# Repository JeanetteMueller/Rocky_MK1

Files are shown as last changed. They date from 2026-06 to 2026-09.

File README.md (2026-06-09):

# Multi-leg Robot with Inverse Kinematics

A DIY walking robot with a configurable number of legs, fully 3D-printed and powered by an ESP32 microcontroller.

Have a look at

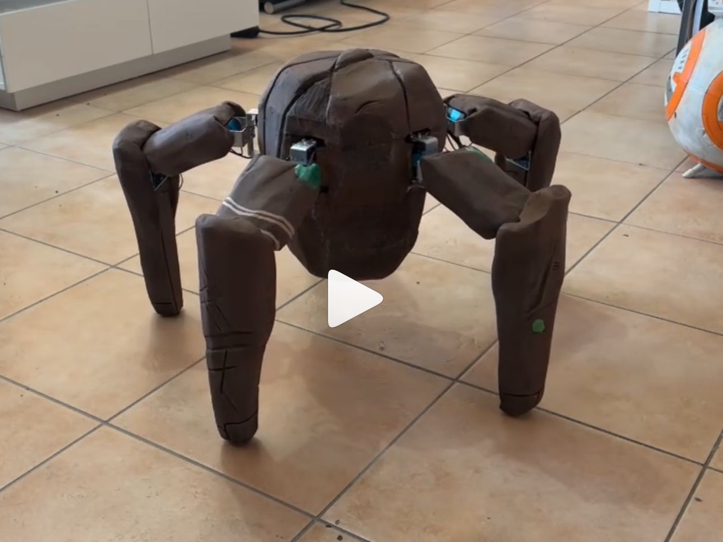
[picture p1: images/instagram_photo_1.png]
Instagram Post (https://www.instagram.com/reel/DXeBLnWDbUL/?igsh=MTJqa2dneTdlbXB5dA==)


## What is This?

This is a multi-legged walking robot designed to support **any leg count and any leg layout** you can imagine. Each leg is its own configurable object — its position around the body, its orientation, and its segment lengths can all be set individually. That means you are not limited to a symmetric pentapod or a classic hexapod: you can build a four-legged scout, a perfectly symmetric octopod, or something deliberately asymmetric with longer front legs, shorter back legs, or unusual angular spacing.

Every leg has three joints driven by three servo motors — Coxa (hip swing), Femur (hip lift), and Tibia (knee). All legs are coordinated so the robot can walk, turn, and perform gestures.

## Asymmetric Robots Are a First-Class Feature

The legs are no longer assumed to be evenly distributed. When constructing the robot, you pass in an array of `RobotLeg` objects, and each one gets its own parameters:

```cpp
static RobotLeg myLegs[NUMBER_OF_LEGS] = {
    RobotLeg(bodyRadius, coxaLength, femurLength, tibiaLength,
             baseFootExtend,     // distance from first servo axis to foot
             baseAngleDeg,       // where this leg sits on the body (degrees)
             rotationOffset),    // how the leg is mounted (degrees)
    // ... one entry per leg, each fully independent
};
```

This unlocks designs like:

- **Spider-style asymmetry:** longer reach in front, shorter rear legs
- **Custom layouts:** legs clustered on one side, or grouped in pairs
- **Mixed geometries:** different femur/tibia lengths per leg for specialized roles
- **Non-uniform spacing:** legs at any angle around the body, not just `360° / N`

The inverse kinematics, gait planning, and special-pose system all read each leg's parameters directly, so an asymmetric build behaves correctly without any special-case code.

## Design

**Body:** Round body with the legs arranged around the perimeter. In the default five-legged build, the body has a radius of approximately 104 mm (center to leg attachment point) and the legs are placed at 72° intervals — but neither the count nor the spacing is hard-wired into the math.

**Legs:** Each leg has three segments:

- **Coxa** — 54 mm, the short hip segment that swings the leg sideways
- **Femur** — 120 mm, the upper leg segment lifted by the second servo
- **Tibia** — 222.5 mm (217 mm shin + 5.5 mm rubber foot pad), the lower leg segment moved by the knee

**Brain:** An ESP32 microcontroller handles all motion calculations, drives the servos via a serial bus, and reads input from the remote control receiver.

**Shell:** All structural parts are 3D-printed.

## How Does It Move?

The robot uses **inverse kinematics** — instead of manually setting angles for each servo, you define where a foot should be in 3D space, and the required joint angles are calculated automatically using trigonometry (law of cosines). This keeps the feet planted on the ground even when the body height, tilt, or yaw changes.

When walking, the robot lifts one or two legs at a time while the remaining legs support the body and push it forward. At low speed, only one leg lifts per phase (more stable). At higher speed, two legs lift simultaneously (faster but less stable). The gait runs as a cyclic phase pattern that adapts automatically to the number of legs in the configuration.

In addition to walking, the robot supports **special poses** — predefined choreographed movements where a pair of legs leaves the gait cycle, moves into a custom position, holds it, and returns to the standing pose. This is used for waving, greeting gestures, or any other interactive behavior.

## Controls

The robot uses a **FlySky receiver (10 channel)** to connect to a FlySky transmitter. All inputs are transmitted to the ESP32 in real time over the IBUS protocol.

Inputs include:

- **Right stick:** walk direction and speed (or steering, depending on mode)
- **Left stick:** body tilt (pitch and roll)
- **Left potentiometer:** body height
- **Right potentiometer:** body yaw rotation
- **Switches:** mode switch (vehicle vs. strafing), special poses, gesture triggers

A switch on the transmitter toggles between two control schemes:

- **Vehicle mode:** forward/backward + steering, like a car
- **Strafing mode:** full directional control, like a tank or RC drone

## Specs

| | |
|---|---|
| **Legs** | Configurable (default build: 5) |
| **Servos per leg** | 3 (Coxa, Femur, Tibia) |
| **Microcontroller** | ESP32 |
| **Coxa length** | 54 mm |
| **Femur length** | 120 mm (default, per-leg configurable) |
| **Tibia length** | 222.5 mm (default, per-leg configurable) |
| **Body radius** | ~104 mm (default, center to leg attachment) |
| **Body height range** | 170–285 mm |
| **Max step width** | 230 mm |
| **Max body tilt** | ±20° |
| **Max body rotation (yaw)** | ±25° |
| **Communication** | FlySky receiver (IBUS) |
| **Servo bus** | Serial (SCServo) |
| **Shell** | 3D-printed |
| **Kinematics** | Inverse kinematics (law of cosines) |
| **Language** | C++ (Arduino framework) |

## Future Plans

- **Sensors:** IMU for automatic body leveling on uneven terrain, foot contact sensors for adaptive gait
- **Reinforcement learning:** Training an AI-driven gait, first in simulation (MuJoCo / PyBullet), then transferring to the real robot
- **Range sensor:** Front-facing ToF sensor for obstacle detection

## Build Notes

### Stuff to Buy

- 3 × leg-count ST3020 serial servos (15 for the default 5-leg build)
- Serial servo controller board
- ESP32 dev board
- FlySky 6/10 channel transmitter + receiver

### 3D Printing

Inside the STL folder you will find files for 3D printing. The end of each filename indicates how many copies to print — for example, a file ending in `x5` needs to be printed five times.

### Prepare the Servos

Use my programmer to assign the servo IDs (1 to N):
[https://github.com/JeanetteMueller/SerialServoIdProgrammer](https://github.com/JeanetteMueller/SerialServoIdProgrammer)

### Required Libraries

- [FlyskyIBUS](https://github.com/derdoktor667/FlyskyIBUS)
- [SCServo](https://github.com/workloads/scservo)

## License & Contact

This is a personal hobby project.

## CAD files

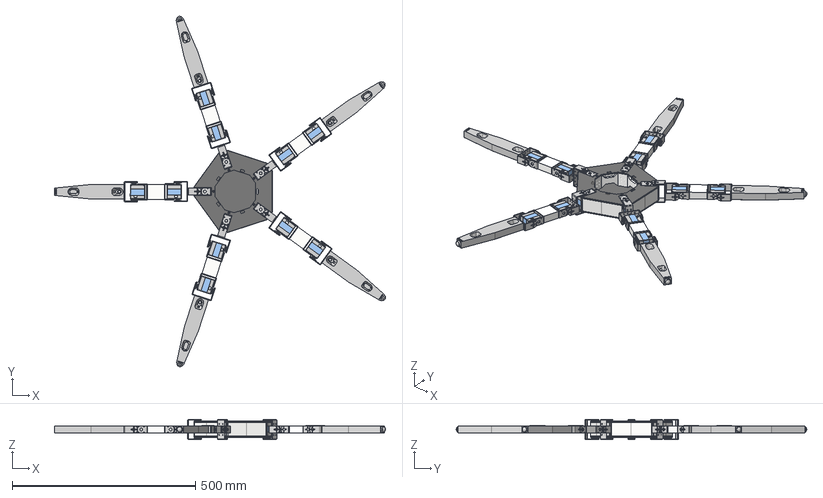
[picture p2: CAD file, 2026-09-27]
STEP/5LegBase v65.step
904.2 x 957.8 x 55.8 mm
SJ-WK00-0054-TOPCABINET_39 x 15
SJ-WK00-0057-BOTTOMCASE_45 x 15
SJ-WK00-0056-MIDDLECASE-TTL_79 x 15
OUTPUTGEAR_12 x 15
SC15-PCB-A_16 x 15
PAIZHING2-54_1 x 15
MAINPCB-PH2-AMP-20210107_1 x 15
FK-AP-019-20210309_1 x 15
WJ-DP00-0002-FK-AP-020_1_1 x 15
FK-US-001_1 x 15
FK-US-002_1 x 15
M20X30_3 x 60
frame
cover_top
cover_bottom
DruckTaster x 4

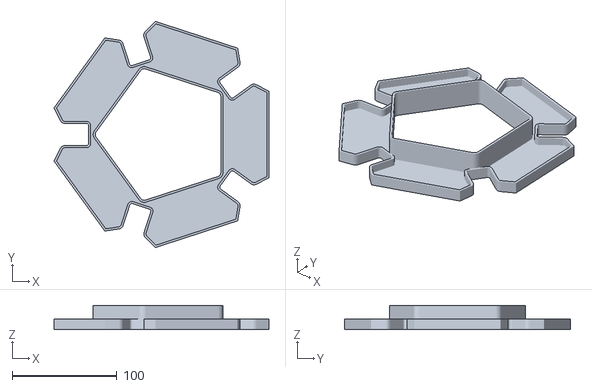
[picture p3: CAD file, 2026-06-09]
STL/TopBodyAddition.stl
205.1 x 215.7 x 23.0

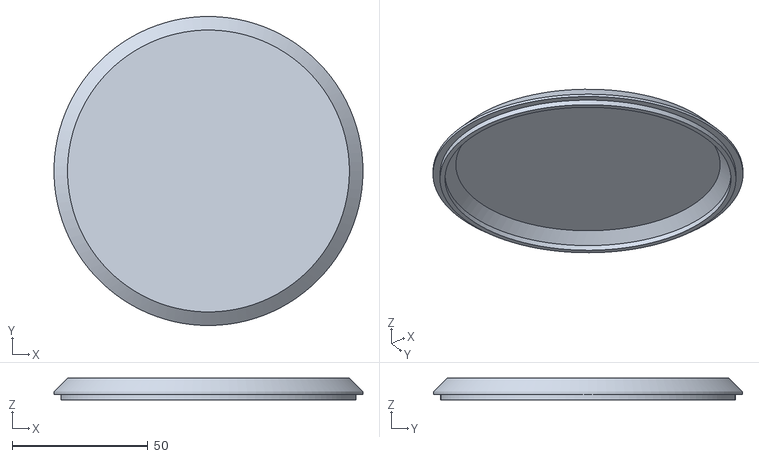
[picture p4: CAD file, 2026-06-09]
STL/head_cover.stl
114.0 x 114.0 x 8.00

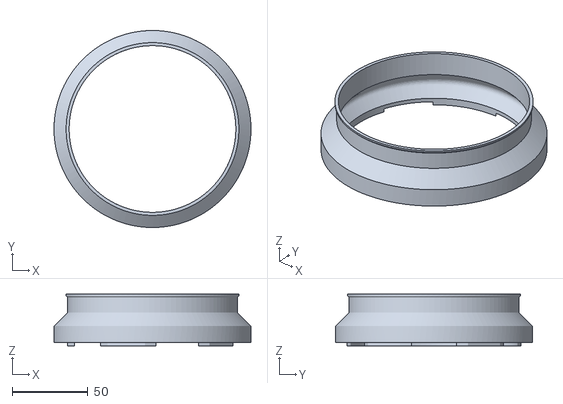
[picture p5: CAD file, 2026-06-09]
STL/head_body.stl
130.0 x 130.0 x 34.0

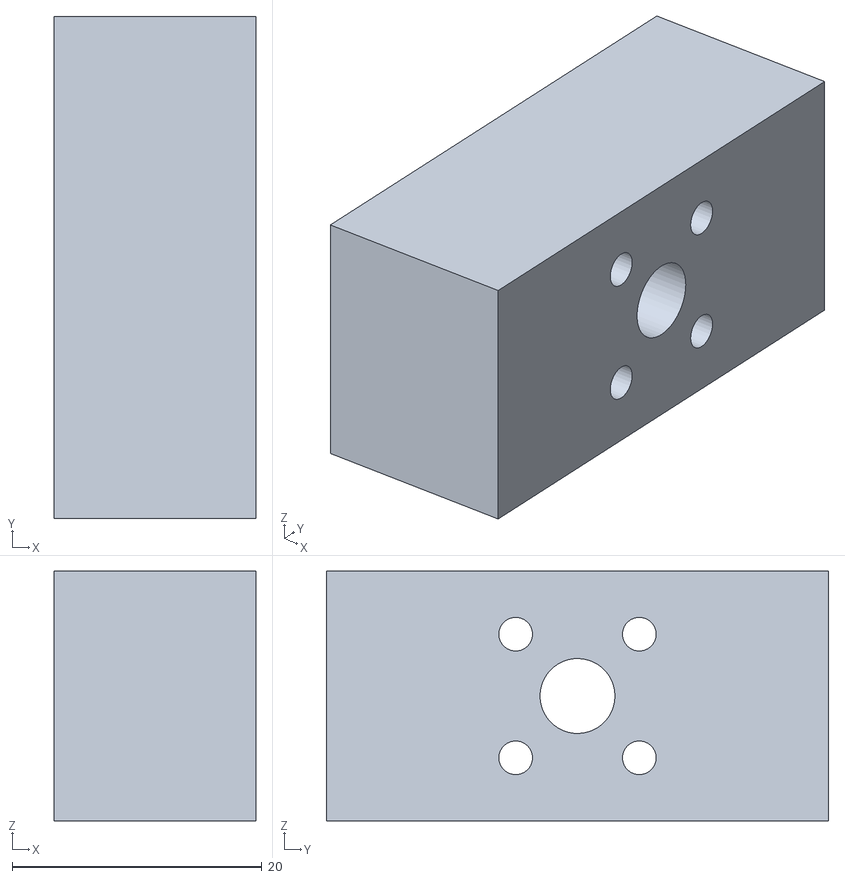
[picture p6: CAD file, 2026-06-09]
STL/thigh x5.stl
16.1 x 40.2 x 20.0

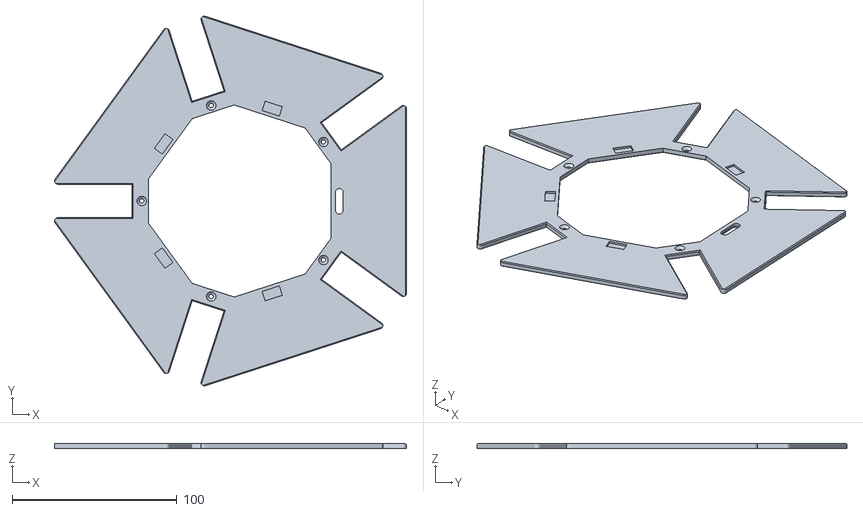
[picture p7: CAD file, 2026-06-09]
STL/cover_top.stl
213.9 x 224.7 x 3.00

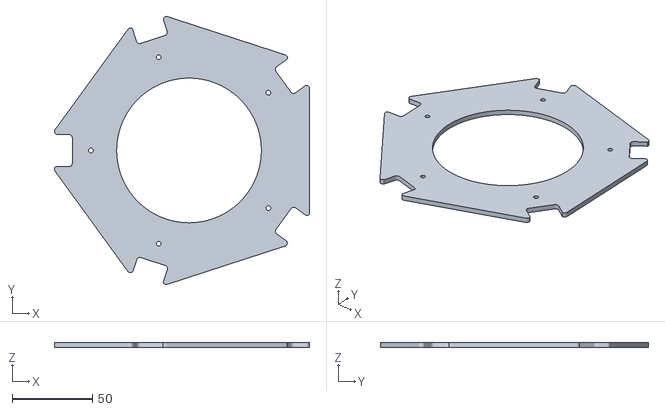
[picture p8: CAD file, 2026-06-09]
STL/UpperBodyAddition.stl
158.7 x 166.7 x 3.00

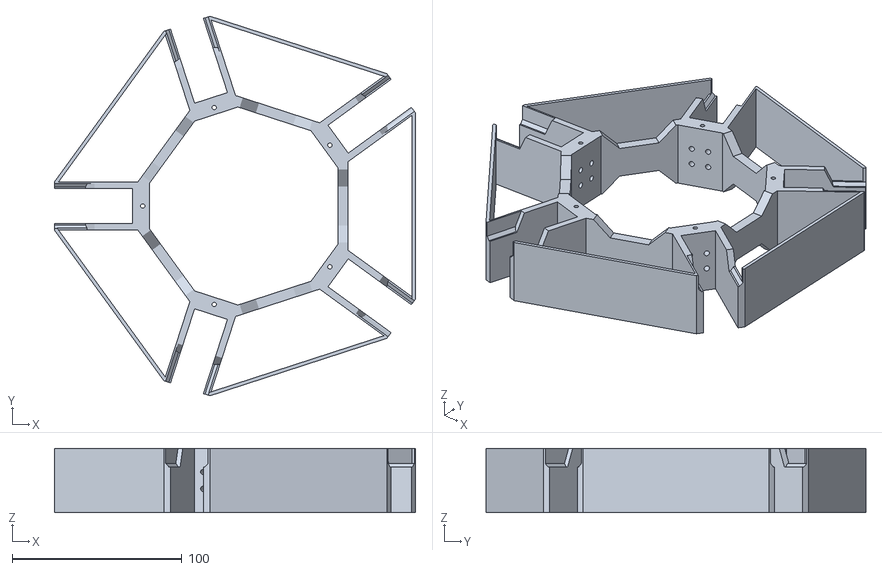
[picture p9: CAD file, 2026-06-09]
STL/frame.stl
212.8 x 223.8 x 38.0

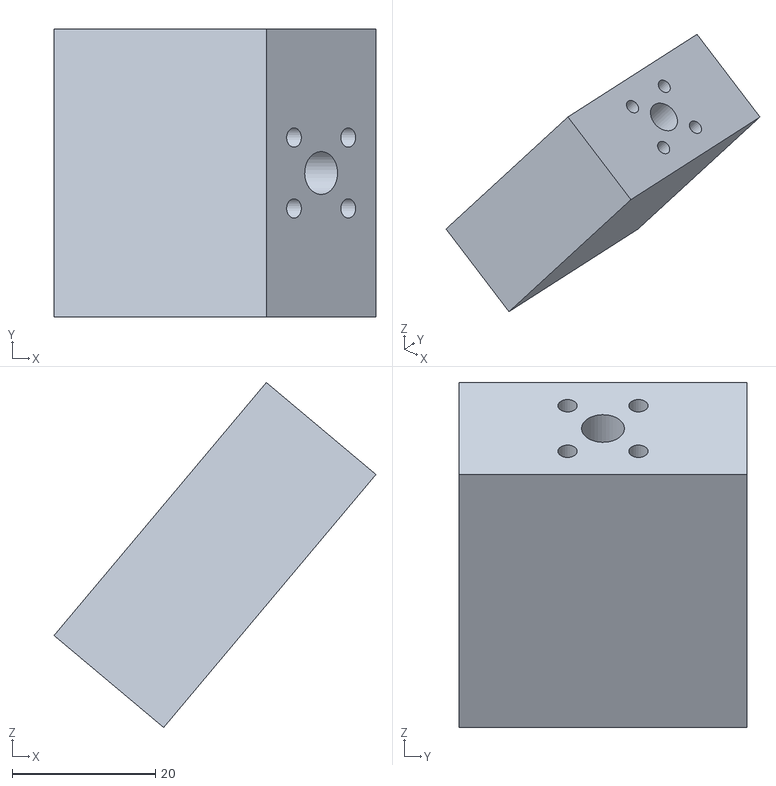
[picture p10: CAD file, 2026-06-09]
STL/thigh v2 x5.stl
45.0 x 40.2 x 48.2

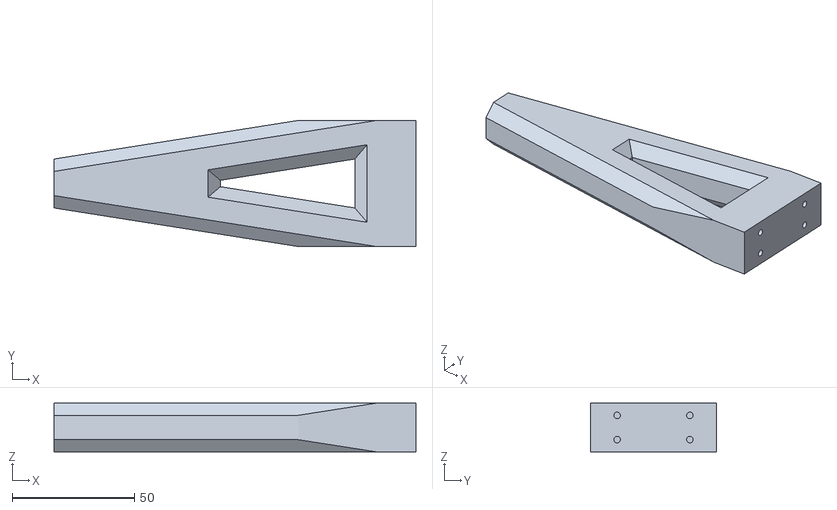
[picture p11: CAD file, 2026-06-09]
STL/shin x5.stl
148.0 x 51.6 x 20.0

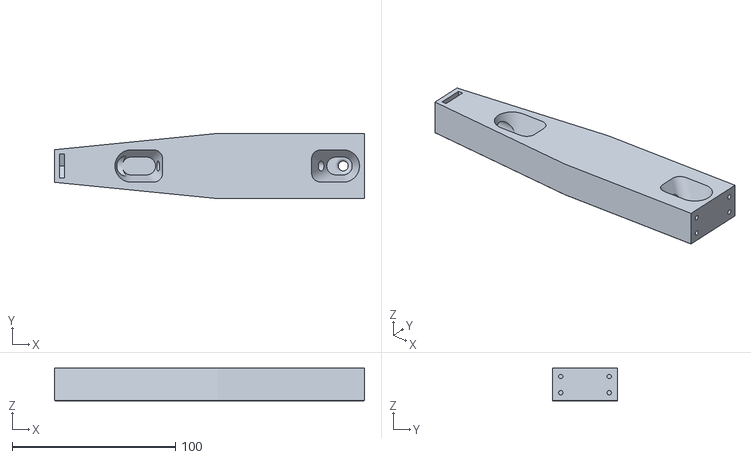
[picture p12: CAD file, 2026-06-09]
STL/shin v3 x5.stl
190.0 x 40.0 x 20.0

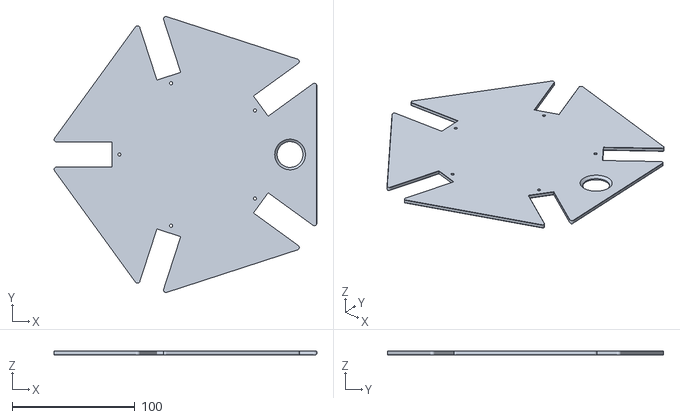
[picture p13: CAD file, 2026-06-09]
STL/cover_bottom.stl
213.9 x 224.7 x 3.00

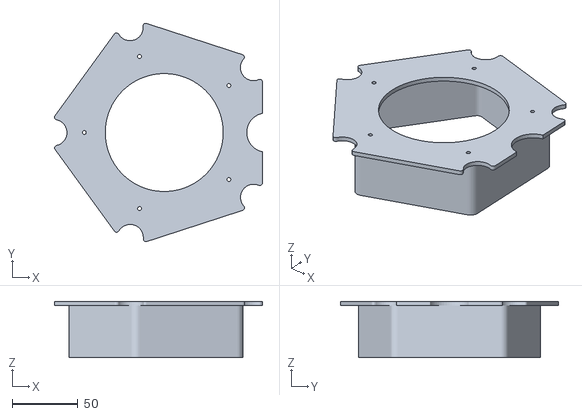
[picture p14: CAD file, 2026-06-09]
STL/LowerBodyAddition.stl
158.7 x 166.7 x 43.0

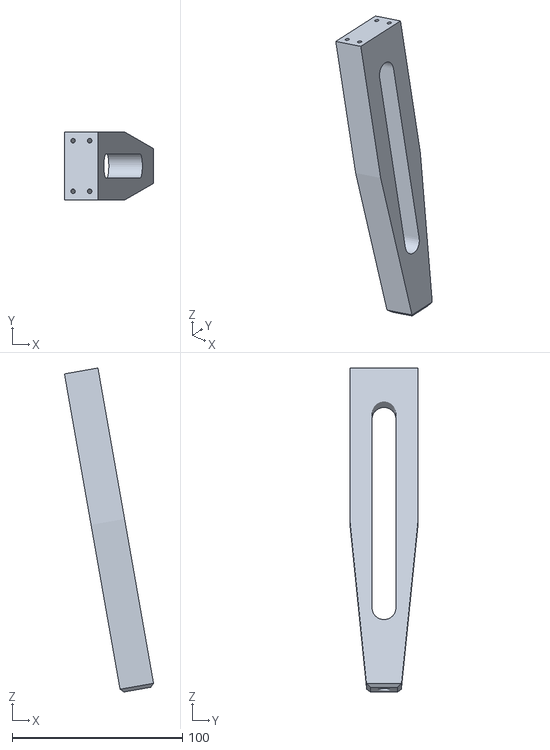
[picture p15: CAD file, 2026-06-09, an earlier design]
STL/shin v2 x5.stl
52.3 x 40.0 x 190.2

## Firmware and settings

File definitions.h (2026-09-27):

/**
 * definitions.h
 *
 * Basis Variablen
 *
 * Autor: Jeanette Müller
 * Datum: 2025
 */

bool debug = false;

SMS_STS st;

#define SERVO_NUM (NUMBER_OF_LEGS * 3) // Number of servos
// u8 servoIds[SERVO_NUM] = {1, 2, 3, 4, 5, 6, 7, 8, 9, 10, 11, 12, 13, 14, 15};
u8 servoIds[SERVO_NUM] = {5, 14, 15, 7, 8, 9, 4, 2, 3, 10, 11, 6, 13, 1, 12};
s16 newPosition[SERVO_NUM];
u16 newSpeed[SERVO_NUM];
u8 newAcc[SERVO_NUM];

const u16 speed = 4000;
const u8 acc = 0;

bool calibrated = false;

#include "../extraCalibrations.h"

// Timing
const uint16_t walkingStepCount = 60;
const uint16_t mainLoopDelay = 5;

// Sizes
const float bodyCenterToLegsCircleRadius = 104.175; // mm
const float coxaLength = 54.0;                      // mm
const float thighLength = 120.0;                    // mm
const float shinLength = 217.0 + 5.5;               // mm // shin + rubber pad
const float minStepHeight = 30.0;
const float centerOfMassShiftFactor = 0.4; // 0.0 = off, 1.0 = all the way to centroid

// Joint limits for Rocky (in degrees). These values used to be hard-coded in
// the library (LegAngles.h) and are now configured centrally here.
//                      { min,    max }
const LegLimits rockyLegLimits = {
    {-65.0, 65.0},   // coxa  (swing)
    {-130.0, 130.0}, // femur (lift)
    {-140.0, 140.0}  // tibia (knee)  = ±(180 - 40)
};

// Position
const float startBodyHeightOverGround = 160.0;            // mm
const float startLegExtend = 280.0;                       // mm
const float heightOffset = 0.0;

// Min/Max Values
const float maxTilt = 26.0;
const float maxRotation = 30.0;
const float maxStepWidth = 230.0;
const float minHeight = 170.0; // mm
const float maxHeight = 285.0; // mm
const float maxRotationBodyOnPoint = 260.0; // mm

// Offset
AxisOffset legAxisOffset = {0.0f, 0.0f};

// Conditions
const bool enableCenterOfMassShift = false;
bool multiLegMovement = true;

// Robot itself
RobotWithKinematics *robot;

// Legs
static RobotLeg myLegs[NUMBER_OF_LEGS] = {
    RobotLeg(
        bodyCenterToLegsCircleRadius, // body radius in mm
        coxaLength,                   // coxa length in mm
        thighLength,                  // thigh length in mm
        shinLength,                   // shin length in mm
        heightOffset,                 // offset from center of mass
        startLegExtend,               // distance of first servo axis to foot
        minStepHeight,                // min height of foot over ground when walking
        0,                            // degree of first servo from front of robot
        -2.0f * 0,
        rockyLegLimits,               // joint limits
        legAxisOffset                 // Lateral axial displacement of the knee {femur, tibia} in mm
        ),
    RobotLeg(
        bodyCenterToLegsCircleRadius, // body radius in mm
        coxaLength,                   // coxa length in mm
        thighLength,                  // thigh length in mm
        shinLength,                   // shin length in mm
        heightOffset,                 // offset from center of mass
        startLegExtend,               // distance of first servo axis to foot
        minStepHeight,                // min height of foot over ground when walking
        72,                           // degree of first servo from front of robot
        -2.0f * 72,
        rockyLegLimits,               // joint limits
        legAxisOffset                 // Lateral axial displacement of the knee {femur, tibia} in mm
        ),
    RobotLeg(
        bodyCenterToLegsCircleRadius, // body radius in mm
        coxaLength,                   // coxa length in mm
        thighLength,                  // thigh length in mm
        shinLength,                   // shin length in mm
        heightOffset,                 // offset from center of mass
        startLegExtend,               // distance of first servo axis to foot
        minStepHeight,                // min height of foot over ground when walking
        144,                          // degree of first servo from front of robot
        -2.0f * 144,
        rockyLegLimits,               // joint limits
        legAxisOffset                 // Lateral axial displacement of the knee {femur, tibia} in mm
        ),
    RobotLeg(
        bodyCenterToLegsCircleRadius, // body radius in mm
        coxaLength,                   // coxa length in mm
        thighLength,                  // thigh length in mm
        shinLength,                   // shin length in mm
        heightOffset,                 // offset from center of mass
        startLegExtend,               // distance of first servo axis to foot
        minStepHeight,                // min height of foot over ground when walking
        216,                          // degree of first servo from front of robot
        -2.0f * 216,
        rockyLegLimits,               // joint limits
        legAxisOffset                 // Lateral axial displacement of the knee {femur, tibia} in mm
        ),
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

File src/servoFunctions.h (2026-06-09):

/**
 * servoFunctions.h
 *
 * Basis funktionen um mit den ST3020 Servos zu arbeiten.
 *
 * Autor: Jeanette Müller
 * Datum: 2025
 */

float ServoDigitalRange_ST = 4095.0;
float ServoAngleRange_ST = 360.0;
float ServoInitACC_ST = 2000;
float ServoMaxSpeed_ST = 4000;
float ServoMaxACC_ST = 100;

s16 calcSerialServoDegree(float degree)
{
  return fmap(degree, 0.0, ServoAngleRange_ST, 0.0, ServoDigitalRange_ST);
}

void initServoPositions()
{
  u16 speed = 2000;
  u8 acc = 0;
  s16 pos = calcSerialServoDegree(180);

  for (uint8_t i = 0; i < SERVO_NUM; i++)
  {
    newPosition[i] = pos;
    newSpeed[i] = speed;
    newAcc[i] = acc;
  }
}

void setDegreeForLegAndServo(uint8_t leg, uint8_t servo, float degree, u16 speed, u8 acc)
{
  uint8_t servoNumber = leg * 3 + servo;

  float target = 180 + degree;

  if (target >= 360)
  {
    target = target - 360;
  }
  else if (target <= -360)
  {
    target = target + 360;
  }

  newPosition[servoNumber] = calcSerialServoDegree(target);
  newSpeed[servoNumber] = speed;
  newAcc[servoNumber] = acc;
}

void finalizeServoPositions()
{
  st.SyncWritePosEx(servoIds, SERVO_NUM, newPosition, newSpeed, newAcc);
}

void calibrate()
{
  Serial.print("Calibrate Servos...");

  delay(1000);

  //// Bein 0 (front)
  // st.CalibrationOfs(5);
  // st.CalibrationOfs(14);
  // st.CalibrationOfs(15);

  // //// Bein 1
  // st.CalibrationOfs(7);
  // st.CalibrationOfs(8);
  // st.CalibrationOfs(9);

  // //// Bein 2
  // st.CalibrationOfs(4);
  // st.CalibrationOfs(2);
  // st.CalibrationOfs(3);

  // //// Bein 3
  // st.CalibrationOfs(10);
  // st.CalibrationOfs(11);
  // st.CalibrationOfs(6);

  // //// Bein 4
  // st.CalibrationOfs(13);
  // st.CalibrationOfs(1);
  // st.CalibrationOfs(12);

  Serial.println(" done");
  delay(500);
}

void moveOneLeg(uint8_t legIndex, LegAngles angles, bool finalize)
{
  // Serial.print("moveOneLeg: ");
  // Serial.println(legIndex);

  LegAngles calibration = extraCalibrations[legIndex];

  setDegreeForLegAndServo(legIndex, 0, calibration.coxaDeg() + angles.coxaDeg(), speed, acc);
  setDegreeForLegAndServo(legIndex, 1, calibration.femurDeg() + angles.femurDeg(), speed, acc);
  setDegreeForLegAndServo(legIndex, 2, calibration.tibiaDeg() + -angles.tibiaDeg(), speed, acc);

  if (finalize)
  {
    u8 singleServoIds[3] = {servoIds[legIndex * 3], servoIds[legIndex * 3 + 1], servoIds[legIndex * 3 + 2]};

    s16 singlePosition[3] = {newPosition[legIndex * 3], newPosition[legIndex * 3 + 1], newPosition[legIndex * 3 + 2]};
    u16 singleSpeed[3] = {3000, 3000, 3000};
    u8 singleAcc[3] = {0, 0, 0};

    st.SyncWritePosEx(singleServoIds, 3, singlePosition, singleSpeed, singleAcc);
  }
}

void moveAllLegs(std::array<LegAngles, NUMBER_OF_LEGS> allAngles)
{
  for (uint8_t legIndex = 0; legIndex < NUMBER_OF_LEGS; legIndex++)
  {
    LegAngles angles = allAngles[legIndex];
    moveOneLeg(legIndex, angles, false);
  }
}

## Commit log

2026-06-09 Rocky now as a stand alone Project with MultiLegRobotWithIK as linked library
    [LowerBodyAddition.stl, TopBodyAddition.stl, UpperBodyAddition.stl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]
2026-06-09 upgrade with custom leg angle limit
2026-09-27 fix for wrong oriented legs
    [definitions.h, system.h]
2026-09-27 STEP file
    [5LegBase v65.step]
